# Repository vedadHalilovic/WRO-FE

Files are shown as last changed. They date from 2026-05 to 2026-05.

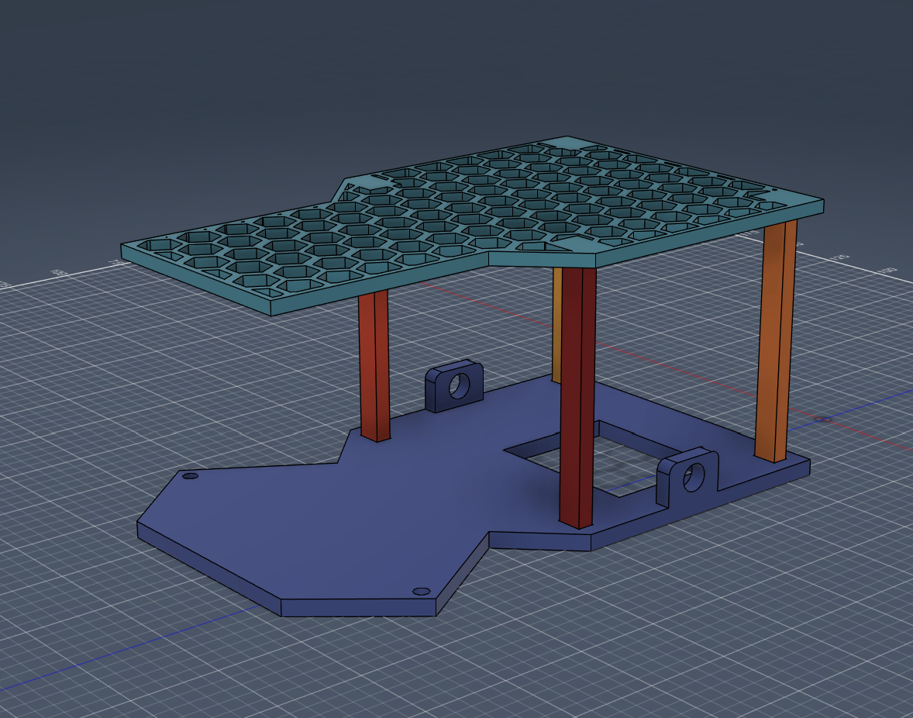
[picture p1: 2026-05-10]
models/parts/chassis/Chassis_skeleton_view.png

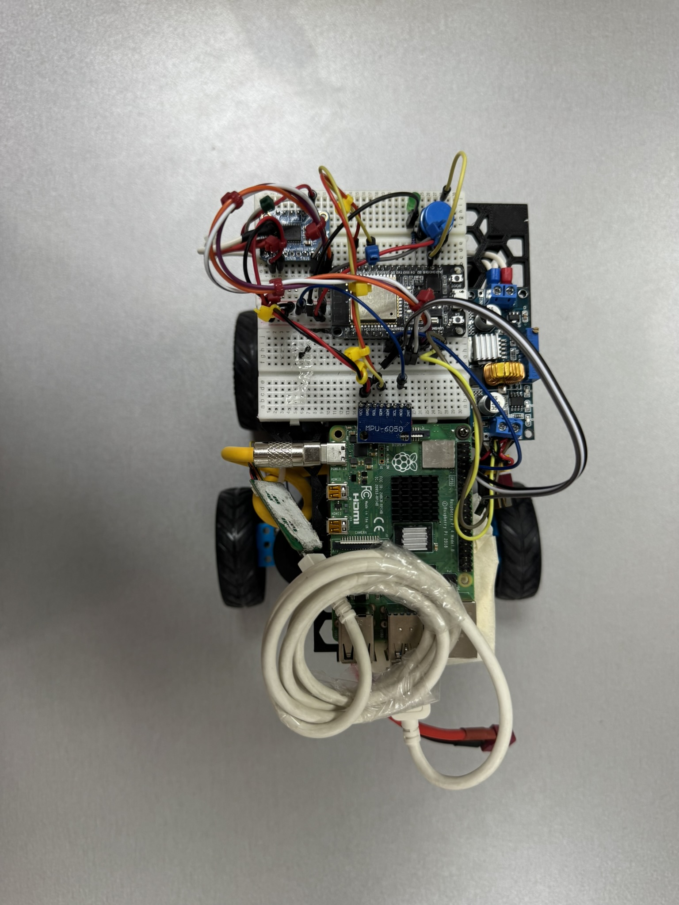
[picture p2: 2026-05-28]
v-photos/v-photo1.JPEG

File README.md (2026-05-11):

## WRO-FE

### **1.1 Team overview**

Team name: MAD Robots

**Team members:**

- Vedad Halilovic-3rd grade of Electrotechnical school in Tuzla

Responsible for construction, electronics, ESP32 code (implementation of said electronics), documentation.

- Ahmed Imsiragic-3rd grade of Mesa Selimovic gymnasium in Tuzla

Responsible for RPI code(python) development and debugging, LIDAR and camera implementation.

- Emir Mujezinovic-3rd grade of Mesa Selimovic gymnasium in Tuzla

**Team mentors:**

- Dejan Bojic- electrical engineer

Responsible for communication with competition organizers.

- Ivan Bosankic-electrical engineer

Responsible for supplying parts and tools.

### **1.2 Mission objectives**

The robot we will be talking about is built to regulations provided by WRO association, as a part of the WRO Future Engineers category.

Our task was to make a self-driving car that will be tested through two rounds, first round where it navigates around a clear track, also known as a free run/open track and a second round where there are added obstacles that need to be avoided accordingly. We achieved this by using a suite of sensors and of course the accompanying code.

The robot's uniqueness lies in it's guidance system, where it uses LIDAR for driving straight and avoiding obstacles as well as using a gyro for 90 degree turns and a camera for detecting obstacle colours. We combined this with RPI 4 model B which takes the raw data from LIDAR and camera and generates navigation data that is further executed by the ESP32 that receives the data and using it controls the steer and drive components (servo and DC motor).

## **Car description**

### **2.1 Challenge 1-open track**

- LIDAR detects walls so the robot stays centerlined and detects an incoming turn.
- RPI generates navigation data in degrees and sends it to the ESP32 and ensures that the robot completes 3 laps and stops in the right spot.
- ESP steers the car according to the data from RPI to keep the robot centerlined and when needed initiate a 90-degree turn
- MPU6050 tracks the yaw and ensures that the robot turned 90 degrees left or right.

### **Challenge 2-obstacle course**

- The robot starts from a parking spot using the logic implemented in the code to navigate out of the said spot.
- Uses LIDAR to keep centreline and to detect obstacles and turns.
- To differentiate two types of obstacles we use a Pi cam module, based on whose data robot knows to go left or right of the obstacle.

### **2.3 Hardware components**

Electronic components that were needed are as follows:

| Component | Function | Model | Mounting/notes |
| --- | --- | --- | --- |
| LIDAR | Keeping the robot centerlined, detecting obstacles | RPLIDAR A1 | Mounted using the provided standoffs and securing it to the base of the construction with M3 bolts |
| Raspberry Pi 4 | Main controller | Pi 4 model B 8GB | Mounted to the top deck of the construction using two M3 bolts |
| AZ-Delivery ESP32 | Gyro/motor controller | ESP32 NodeMCU Module WLAN WiFi Development Board Dev Kit C V2 with CP2102 | Mounted to breadboard |
| Servo motor | Steering the robot by turning the steer wheels | Hitec HS-422 | Mounted using a custom made bracket, for fasteners M3 and M4 bolts with corresponding nuts were used |
| 12V DC drive motor  | Driving/propelling the robot | 25GA-370 | Mounted using PETG 3D printed mount and secured to the lower deck/base of the construction using M3 bolts and adhesive |
| Motor driver | Controls the motors using PWM signals received from the ESP32 and powering the drive motor from the 11-12V source(battery) | Adafruit TB6612 motor driver | Mounted to breadboard |
| MPU-6050 | Used to determine when the 90-degree turn is achieved | MPU-6050 | Mounted to breadboard |
| Buck converter | Stepping the voltage from 11-12V to 5V suitable for 5V logic electronics | 5A high current | Mounted using adhesive to the top deck of the construction |
| 11.1V Li-Po battery | Powering the robot | GOLDBAT 11.1V 5000mAh 3S 50C LiPo RC Battery | Mounted using adhesive |
| Pi camera | Detecting the obstacle colour | Raspberry Pi Camera Module 2 | Mounted to the top deck |

### **2.4** **Mechanical design**
<p align = "center">
  iso_front_view
</p>

- **Base/lower deck:** solid PETG 3D printed part.
- **Top deck:** PETG 3D printed with honeycomb pattern for weight savings, attached to lower deck using four 3D printed pillars.
- **Camera mount:** 3D printed beam attached to the top deck using adhesive, camera is pointed down at a 15-degree angle for more accurate readings with less ambient light interference.
- **Cooling system:** heatsinks on RPI and buck converter.
- **Fasteners:** M3 and M4 bolts with corresponding nuts.
- **Drivetrain:** connected to drive wheels using ⌀4mm D-shaped axle(shaft) with a 3D printed spur gear (module 2, 10 teeth) with the same being connected to the motor with a 14 teeth module 2 spur gear. Driveshaft side movement limited using ⌀4mm shaft collars.
- **Steering system:** Steering system uses a combination of 3D printed parts and pre-made aluminium profiles as well as Lego spur gears. Axles are 3D printed, servo is connected to one of the gears, multiple gears are used as to clear the LIDAR. Everything is mounted using M3, M4 bolts and 4mm shaft collars.

### **2.5 Electrical design**

#### **2.5.1 Buck converter**

We are using a 5A buck converter that powers all electronics with the exception being the drive motor.  
It's role is to step the voltage down, so it is safe for our controllers and sensors.  
A heatsink was installed to provide adequate cooling because of high currents.

#### **2.5.2 Buttons**

Buttons provide a way to initiate our programs without accessing the RPI remotely per the regulations. First button is used to initiate the code for the first challenge, with the second button being used for the second challenge.

 **2.5.3 Motor driver**  
 
Adafruit dual H-bridge TB-6612 motor driver was chosen because it best fit our use case, with it being compact, supporting up to 1.2A continuous on 5-13V DC.  
It controls the motor movement direction by applying 5V to AIN1 or AIN2.  
Motor speed is controlled via a PWM signal from the ESP32 to the driver's PWMA pin.

(electrical schemes are in the schemes folder)

**3 Software design**

**Language:** Python (RPI side), C++ (ESP32 side)  
**Image processing:** OpenCV

**Modules:**

- **Position tracking:** LIDAR
- **Turning:** Gyro
- **Drive control:** ESP32
- **Corrections** are made using PD-based steering

**Flowcharts:**

- **System startup:** Power on → Initialize sensors → Calibration → Ready
- **Challenge 1:** LIDAR keeping robot centred driving forward→ LIDAR detecting a turn→ gyro executing a 90-degree turn → robot completes 3 laps → stops in segment it started from
- **Challenge 2:** LIDAR keeping robot centred driving forward → LIDAR detecting an obstacle → camera turning on and detecting the colour → robot passing the obstacle on the correct side → loop until finish → stop

**Uploading the code (for reproduction purposes)**

**IDE-s used:**

- **Arduino IDE (for ESP32)**
- **Thonny (for RPI)**

**Libraries (ESP32):**

- &lt;Arduino.h&gt; - used to enable Arduino API
- &lt;ESP32Servo.h&gt; - used for servo control
- &lt;Wire.h&gt; - enables I2C communication
- &lt;Adafruit_MPU6050.h&gt; - used for interacting with/controlling the gyro

**Libraries (RPI):**

- rplidar - needed to use the LIDAR
- serial - enables communication between ESP32 and RPI
- time - enables time.sleep() function

**Uploading the code to ESP:**

After installing libraries for ESP32 you need to download ESP32 in Arduino IDE to be able to upload your code, as well as CP210X drivers.

Open Arduino IDE → connect ESP to your computer → select your ESP32 board in board manager → click the upload → after the upload has finished press the RST button on ESP32

This file in combination with the codes from src folder and schemes from schemes folder can be used to replicate our robot(feel free to try)

<br/><br/>

<br/>\*\*

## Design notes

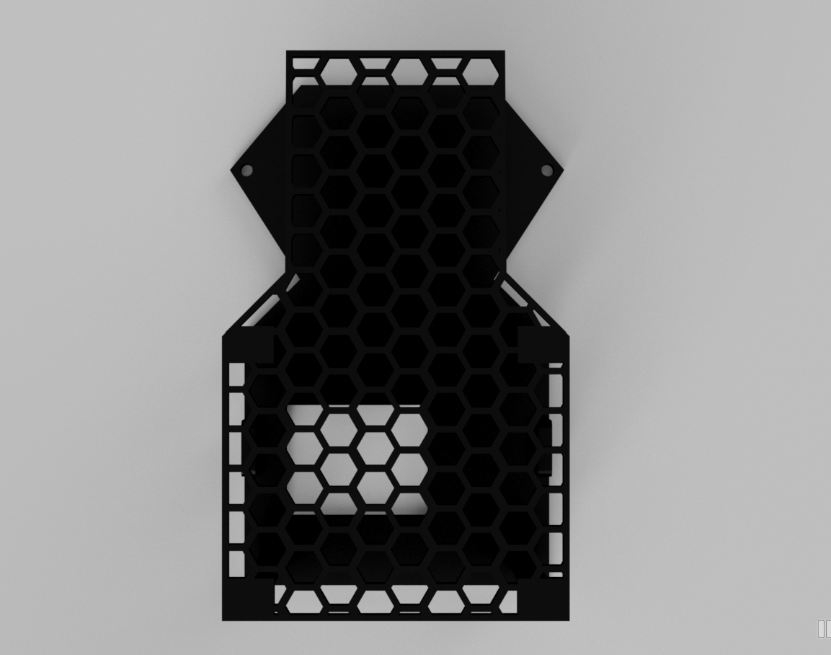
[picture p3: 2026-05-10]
models/renders/top_view_orthographic.png

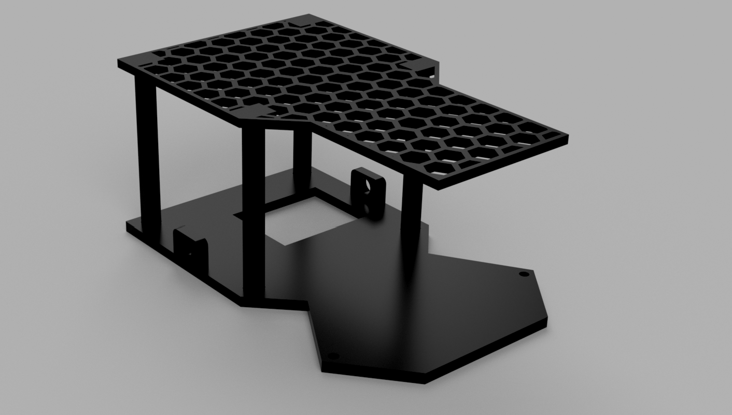
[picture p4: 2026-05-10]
models/renders/iso_front_view.png

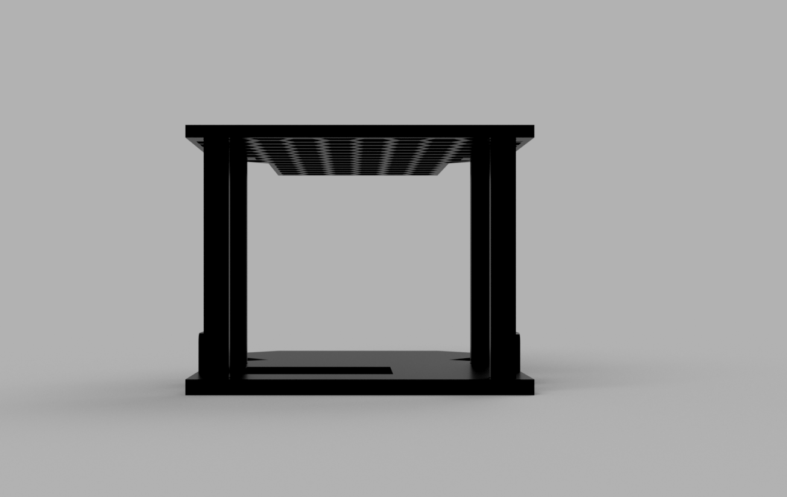
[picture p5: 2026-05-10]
models/renders/rear_view_orthographic.png

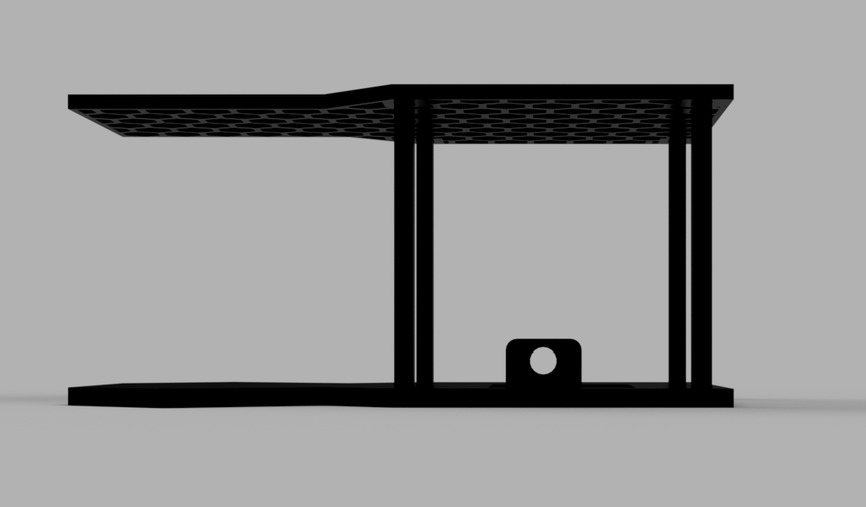
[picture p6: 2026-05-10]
models/renders/side_profile_orthographic.png

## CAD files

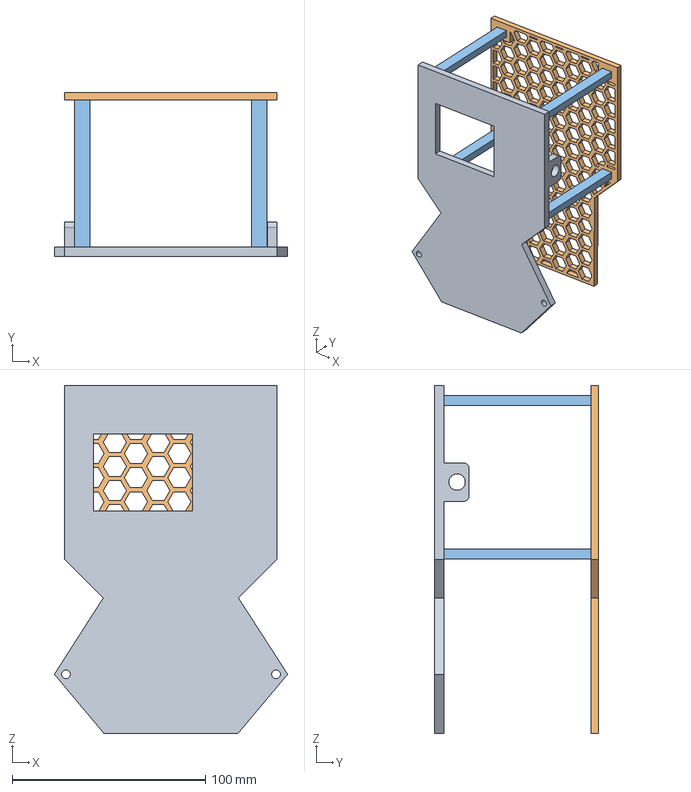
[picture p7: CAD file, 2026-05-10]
models/parts/chassis/Chassis_skeleton_view.step
120.7 x 85.0 x 180.1 mm

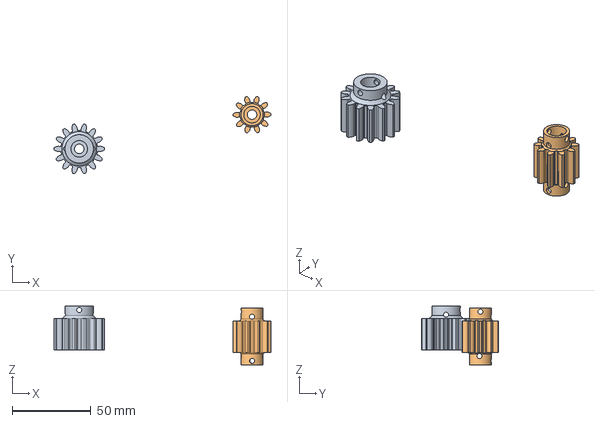
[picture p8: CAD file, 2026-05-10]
models/parts/Spur_gears/Spur_gears_design.step
137.5 x 49.0 x 37.3 mm

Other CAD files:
models/parts/Spur_gears/Spur_gears_design.3mf
models/parts/Spur_gears/Spur_gears_design.stl
models/parts/chassis/Chassis_skeleton_view.3mf
models/parts/chassis/Chassis_skeleton_view.stl

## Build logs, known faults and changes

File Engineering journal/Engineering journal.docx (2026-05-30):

# 1. Mobility & Mechanical Design

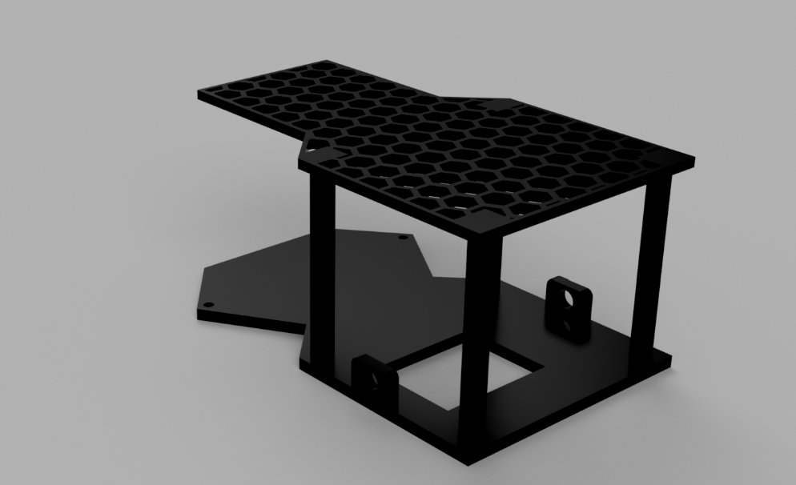
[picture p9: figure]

chassis render

As can be seen in the render above, our 2026 WRO chassis consists of two distinct parts, bottom and upper plate (lower and upper deck).

This design is a reflection of multiple constraints and insights gained through iterations. Our main constraint was the maximum width allowed per the 2026. rules which meant that the battery had to be placed on the underside of the top deck, which was not our first choice for the obvious reason of robot’s weight distribution and centre of gravity.

In the first iteration the battery was placed on the lower deck, but we knew from the start that we could not show up with that design as it measured in at 22.6cm in width, so a second chassis was designed (the one that is being described in our journal).

Key changes between the first and second iteration is the battery placement as I already mentioned, but also the maximum width as the new chassis measures in at 12.75cm at its widest point. This helps our turning radius, also the design in itself is much more efficient as less space is left unused, especially in the front half where the LIDAR is placed.

In the second iteration the honeycomb design on the bottom deck was replaced in favour of a solid PETG 3D printed surface for ease of mounting our components, while the upper deck has kept the honeycomb and has also been lengthened to accommodate the battery as well as all the sensors including the RPI and ESP32.

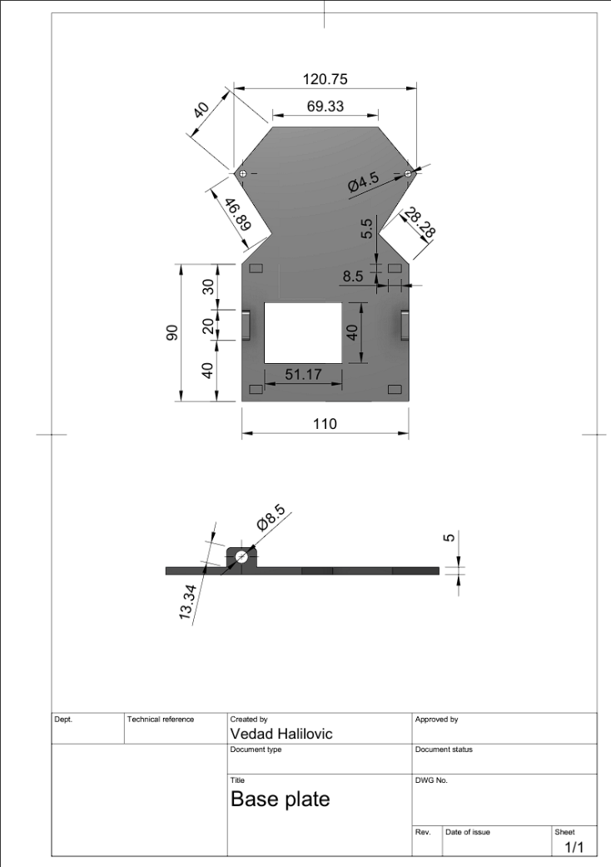
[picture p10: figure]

Technical drawing of the base plate with dimensions in 1:2 scale

With the length of 180mm(18cm) and the width of 120.75mm, this base plate fits inside the maximum allowed dimensions per the 2026. rules.

Placement of components was designed to give the robot a 60/40 weight distribution with 60% on the drive axle and 40% on steering wheels.

In the front half we placed our LIDAR on provided standoffs, so it has unobstructed 180-degree view. LIDAR is secured at 4 points using M2 bolts provided by the LIDAR manufacturer.

Under the lidar sits the first spur gear with the steering axles mounted to it using M4 bolts and corresponding nuts. Spur gear is fixed to the base plate using a 4mm stainless steel shaft, with 4mm shaft collars on both sides. Steering hubs that connect wheels to the steering system are connected to steering axles at two point parallel to one another, and to the base plate using the pre-drilled holes and M4 bolts with corresponding nuts. Holes are designed at 4.5mm in diameter due to unavoidable shrinkage associated with 3D printing.

Steering hubs are premade components, and spur gears used in the steering system are repurposed LEGO spur gears. Behind the LIDAR, servo motor is mounted. Spur gear on the servo has half the teeth compared to the spur gear connected to the steering axles. This was done to ensure a more precise system, and to reduce the stress on the servo motor itself.

In the back half of the base plate the drive motor is located on its mount. The drive motor is connected to the axle with spur gears, more precisely a 14 teeth module 2 spur gear with a 20-degree pressure angle. The spur gear is fixed to the motor with a 4mm shaft collar.

The spur gear connected to the axle is a 10 teeth module 2 and also shares the 20-degree pressure angle. This gear is fixed to the drive axle using 4mm shaft collars inside the spur gear.

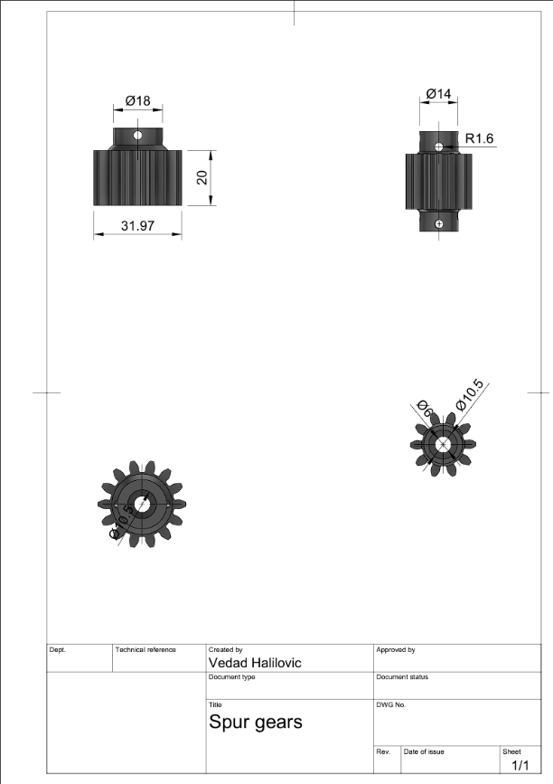
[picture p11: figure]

Spur gears drawing

As can be seen in the technical drawing above both gears share the 20mm height, as well as the inside diameter of 10.5mm, even though the shaft collar has an outside diameter of 9mm, due to shrinkage of plastics during 3D printing inner diameter of our gears was set to 10.5mm to compensate for the mentioned shrinkage.

We chose 14:10 ratio because our motor is a high torque model, which means that it comes geared from the manufactuer, and only provides 160rpm on max speed. Testing showed that the best ratio of speed and torque was offered by 14:10 ratio, we also tried 1:2 and 1:3 but during testing we found that this appreoach sacrifices too much torque and that the robot was becoming much less precise because eof this.

Module 2 was chosen because in our very first iteration of the spur gear system with the 2:1 ratio and module 1 gears were skipping a lot and that obviously created issues with movement, as the teeth would slip. That lead us to use module 2 for all other iterations and testing. We used a 20 degree pressure angle from the start, because the higher pressure angle offers stronger teeth(wider base), with a trade-off being louder operation compared to 14.5-degree pressure angle, but as that is not an important factor to us we prioritised the shear strength to avoid teeth snapping, which is also a reson for the 20mm heigth which helps us distribute the load accros the gear.

Below you will find a 3D render of the spur gears which better illustrates the design.

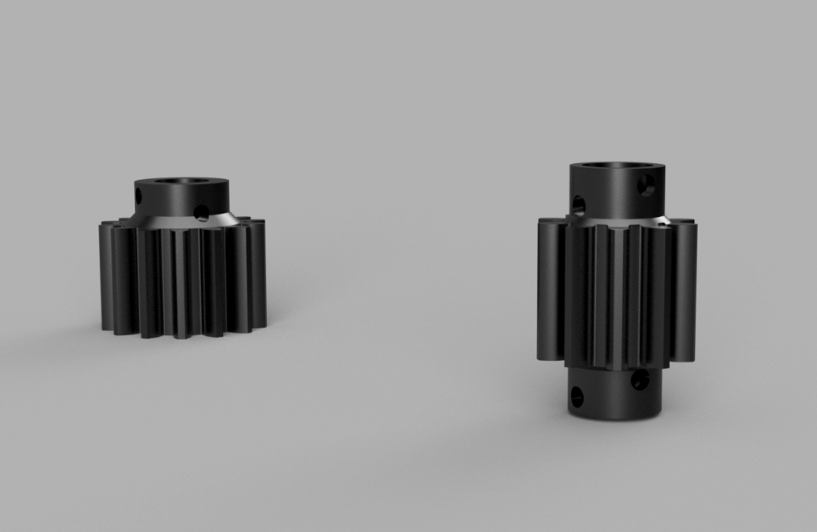
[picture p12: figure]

Spur gears render

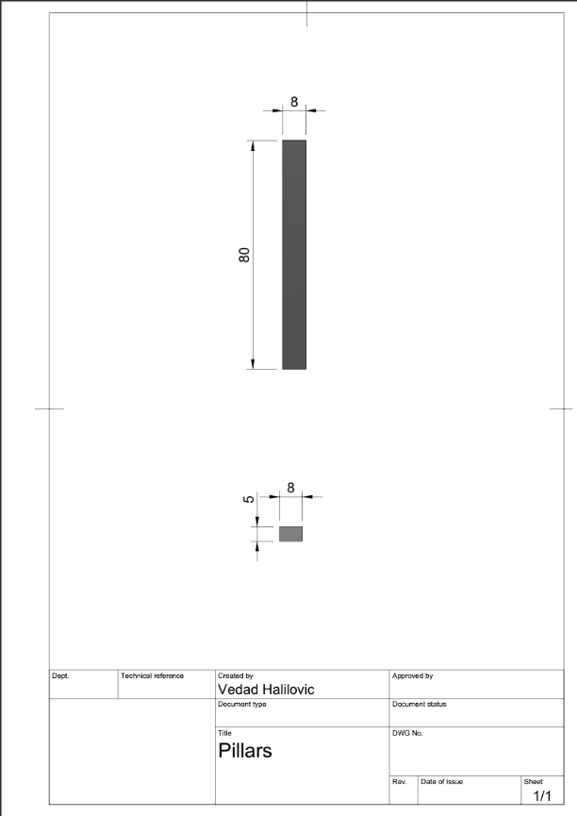
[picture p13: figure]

Pillar technical drawing

Four pillars connect the bottom and top deck of our robot. We chose an 85% infill to ensure mechanical stability so that they would not accidentally bend. They sit in the cutouts on the bottom plate, with the same cutouts being found on the top plate as well. Initially we wanted to use a lighter desing with a 20% infill, but as they have to carry the weight of the battery and not just the electronics we opted for a more heavy-duty approach.

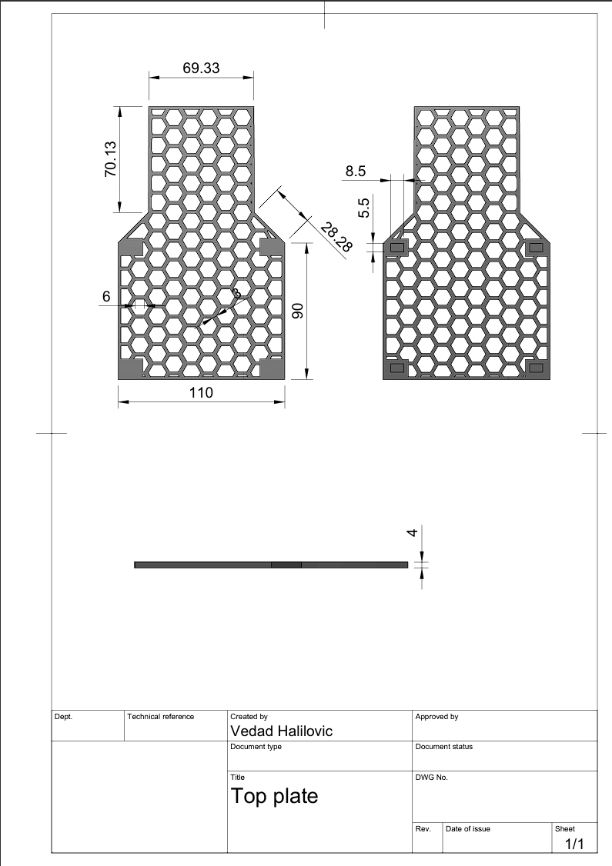
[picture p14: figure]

Top plate technical drawing

For our second iteration the top plate has been lenghtened to accommodate both the electronic components and the battery.

We went with a honeycomb design, because it offers weight savings while still giving us enough structural rigidity. For the first iteration of this desing we tried a 2mm thickness, but found that it bends too much and is prone to cracking, so for the second iteration we increased the thickness to 4mm as can be seen on the technical drawing above. For infill we went with 85% because of the dense honeycomb structure. The top plate has an overall length of 18cm, with the widest point coming in with the width of 11cm. The specific shape was chosen for space saving, that is reducing unused space, as the front half is just wide enough to fit a Raspberry Pi, with the back half being wider to accommodate other components, with the breadboard.

In the front half the RPI is placed together with the Pi camera and in the back half ESP32 with the motor driver, MPU and buck converter are placed.

# 2. Power & sensor architecture

Sensor list:

Name/manufacturer | Model | Use | Current draw
12VDC drive motor | 25GA-370 | Moving the robot | 700mA-1A
Servo motor | Hitec HS-422 | Steering the robot | 600mA-800mA
Pi camera | Raspberry Pi Camera Module 2 | Detecting the obstacle colour | 250mA-300mA
RPI 4 | Model B 8GB | Calculation of navigation data | 1A-3A
RPLIDAR | A1 | Navigation | 600mA
ESP32 | Wroom/DevKit | Management of motors and other sensors | 240mA-500mA
MPU | MPU 6050(6 axis MPU) | Calculation of 90 degree turns | 5mA
Adafruit TB6612 | TB6612FNG | PWM control of 12VDC motor | 10μA

Total system draw ranges from 3.4 – 6.2A depending on the circumstances for instance on idle it is around 3.4, while during the second-round execution 6.2A may be reached.
important to note is that 600-800mA from this sum is the DC motor which does not eat into our buck converter’s power budget.

For our battery we have chosen the GOLDBAT 5000mAh 3s LiPo battery as it offers a 250A continuous current draw, what that means for us is that our voltage does not drop even on startup or under peak loads and the battery stays cool. Only downside to running this battery is the weight penalty with the battery coming in at 429g on its own.

Since the battery has a nominal voltage of 11.1V a buck converter is needed so that the voltage could be stepped down to 5V for other electronics, while the drive motor runs directly off the 11.1V pack.

Buck converter that is being used can output 5-6A with the heatsink that is installed, because we were space constrained, we opted for one high power buck converter rather than two lower power models.

RPI was needed due to our choice of using LIDAR instead of ultrasonic sensors as LIDAR uses USB connection.

For the camera it was not as much of a necessity as it was convenient, because we figured we need the RPI for the LIDAR, we might as well use a Pi camera instead of a standalone module like openMV H7 and similar modules which was also a weight and a space saving measure. All of that combined with RPI’s computational power made it an obvious choice.

TB6612 was chosen because it is compact and much more efficient than older BJT motor drivers with minimal voltage drop due to its use of CMOS. Also, it has a smaller power draw for its own internal components which creates a smaller voltage drop on the ESP32’s 3.3V rail used to power it.

ESP32 is being used to control all the sensors with the exceptions being the Pi camera and LIDAR.
There are multiple reasons for this but the main one being that it was much easier for us to program it in two different codes one on RPI sending the navigation data and ESP32 executing it, that is communicating with said sensors.

Because the 2026 rules dictate a solid rear axle that is no differential drive it was decided to add an IMU, with reasoning that rear wheels spinning at the same speed cause the front wheels to sometimes skip, which produced inconsistencies in 90 degree turns. By adding an IMU this problem was alleviated, with the IMU tracking robot’s yaw and it keeps turning until the robot achieves 90 degrees.

Servo motor on the robot is Hitec HS-422 was chosen mainly for its availability in the region, but also for its torque which was needed to keep the steering smooth on our 1.5kg robot.

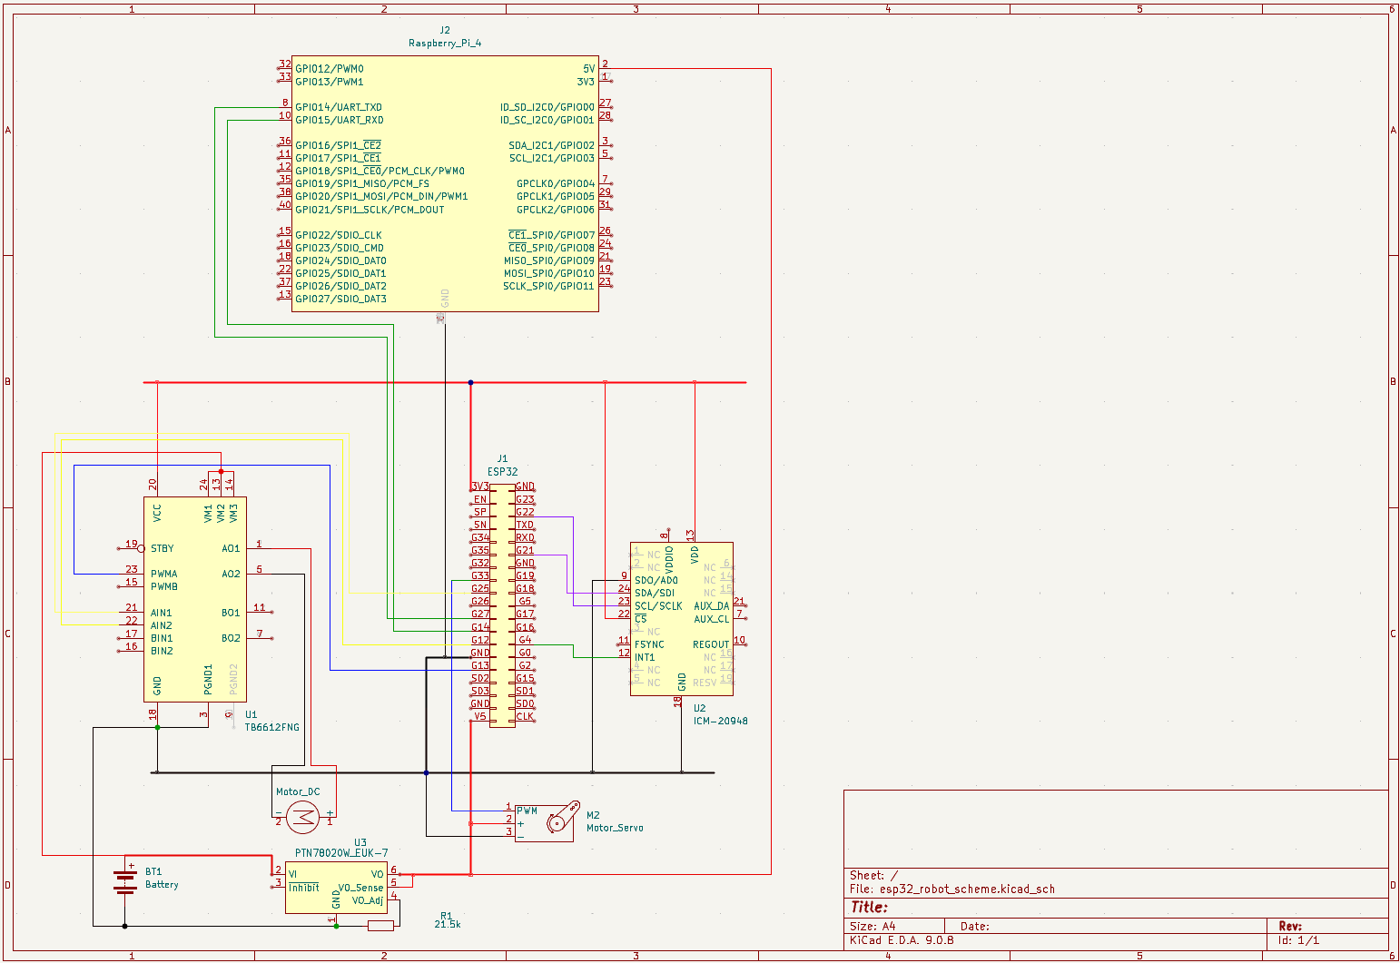
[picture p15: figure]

Electrical scheme

In the picture above is presented a wiring diagram/schematic of our robot, except for the camera and LIDAR which we could not obtain in the software that we are using (KiCAD).

As can be seen on the diagram above ESP32 and RPI communicate using TX/RX pins (pins 27, 14 on ESP32). We refrained from directly using TX/RX pins on ESP32, rather we created a virtual serial port/monitor, because we were having issues with inconsistent data transfer using UART, that led us to our unorthodox solution, as a result of which we had to switch to baud rate of 9600 from 115200. In the end the 9600bps did not limit us in any way, furthermore it allowed us to be more flexible with our pins because now we can use almost any pin on our ESP32 for communication with the RPI.

For the MPU we have decided on the I2C protocol for seamless integration with the ESP32, for the calibration we were running a 750 sample for loop as soon as the robot is powered on, during which time the robot remains stationary(both servo and drive motor are disabled) so we can get an accurate calibration with minimal, gyro drift which is further mitigated by using a filter in the updateYaw() function which is further explained in the Software Architecture & Obstacle Strategy section.

But on our second iteration we discovered a function in the library which calibrates the gyro, and also updates all 6-axis, after which we just read the axis that we need. The function in question is mpu.calcGyroOffsets(), and the function for updating the axis is mpu.update().

The TB6612FNG is connected to pins 13, 12, 25(PWMA, AIN2, AIN1). By altering PWM signals on these pins, we control the polarity(direction) and speed of our drive motor. Pins AIN1 and AIN2 control the polarity of the motor, while the PWMA controls the speed which in the code is defined as driveSpeed that is of the integer type.

VCC pin supplies the driver with 3.3V for the logic side that is for powering the transistors, important to note is that the TB6612FNG uses a shared(common) ground between the high voltage and low voltage side.

AO1 and AO2 pins are outputs of the drivers that connect to the motor’s positive and negative terminals.

VM pins supply are connected to 12V, and they supply the motor with power. As can be seen on the diagram above VM pins are connected directly to the battery bypassing the buck converter. For all 12V connections and RPI power line a 0.75mm wire is used to handle large currents without added resistance and heat.

Servo motor is using 5V from the buck converter and is grounded with all the other components. Servo’s signal wire is connected to pin 33 on ESP32. We opted for a 5V servo because it provided enough torque while being significantly lighter than its 12V counterparts.

ESP32 gets its power from the buck converter and steps it down further to 3.3V so it is safe for the IMU and TB6612FNG, it was decided to power these components directly from ESP’s 3.3V rail because the current that they draw is extremely small (measured in microamps).

RPI is powered through its type-C interface using 5V from the buck converter, as all the other components it also has a common ground so as not to cause interference in communication with ESP32 due to difference in potentials.

RPLIDAR is placed at the front of the robot so it has unobstructed 180-degree view of the track, above the LIDAR Pi camera is placed so it could reliably read colours of the obstacles.

MPU is placed on the top deck as far from the drive motor as possible as to limit the EMI, further steps have been taken to limit EMI such as twisting motor’s power lines and having the TB6612FNG on the opposite side of the breadboard also helps alleviate this issue.

Buck converter is placed on the far-right side so its heatsink gets as much cool air over it as possible to be able to passively dissipate the heat from the 5A running through it.

Placement of servo was mainly dictated by the position of the LIDAR with the servo being positioned right behind it.

ESP is placed in the middle of the top deck so as to be close both to the MPU, TB6612FNG and RPI.

3. Software Architecture & Obstacle Strategy

Open Challenge – ESP32 Actuation Layer

# 1. System Overview

The ESP32 is the robot's actuation layer. It receives high-level commands from the Raspberry Pi over UART, drives the motor and steering servo, and uses an MPU6050 gyroscope (IMU) to execute closed-loop 90° turns. The firmware is written in Arduino C++ and is structured around a non-blocking event loop with a dedicated state flag (isTurning) that separates straight-line driving from turn execution.

Architecture Summary

Layer 1 – Communication: HardwareSerial(2) receives commands from RPi at 9600 baud (RX=27, TX=14).

Layer 2 – State Control: isTurning flag gates command parsing; updateYaw() runs every loop iteration.

Layer 3 – Actuation: Servo on GPIO 33 for steering; TB6612-style driver (AIN1/AIN2/PWMA) for motor.

# 2. Hardware Pin Map

Pin / Bus | GPIO | Role
ledGreen | 2 | Status LED — blinks during startup, solid ON when ready
button_start | 15 | INPUT_PULLUP start button
pwma | 13 | Motor speed (PWM via analogWrite)
ain1 | 25 | Motor direction control A
ain2 | 12 | Motor direction control B
steeringServo | 33 | Steering servo signal
I2C SDA | 21 | MPU6050 data line
I2C SCL | 22 | MPU6050 clock line
UART2 RX | 27 | Receive from Raspberry Pi
UART2 TX | 14 | Transmit to Raspberry Pi

# 3. State Machine

The firmware operates as a four-state FSM driven by the isTurning flag and the startup sequence:

State | Entry Condition | Actions | Exit Condition
STARTUP | Power on | Blink LED; wait for button; initialise Serial, UART, I2C | Button pressed
CALIBRATE | Button pressed | mpu.calcGyroOffsets() — robot must remain still | Calibration complete
READY / DRIVE | Calibration complete; sends 'a' to RPi | Parse UART commands; apply steering angle; drive at driveSpeed | Receives 'l', 'r', 'n', or 'm'
TURNING | startTurn() called | Reduced speed; full servo lock; checkTurnProgress() each loop | yaw reaches targetYaw; sends 'h' to RPi

The isTurning flag is the central gate of the FSM. While isTurning is true, incoming UART commands are ignored completely — this prevents a new steering angle arriving mid-turn from interfering with the gyro-controlled manoeuvre.

# 4. IMU Integration — updateYaw()

The MPU6050 is used exclusively for yaw (Z-axis rotation) tracking. It is updated on every loop iteration to maximise angular resolution during turns:

void updateYaw() {

mpu.update();

yaw = mpu.getGyroAngleZ(); // integrated gyro angle in degrees

static float lastPrintedYaw = 0;

if (abs(yaw - lastPrintedYaw) > 0.5) { // only print on meaningful change

Serial.print("Current Yaw: ");

Serial.println(yaw);

lastPrintedYaw = yaw;

}

}

mpu.getGyroAngleZ() returns an accumulated (integrated) angle — it measures rotation relative to the heading at power-on, not absolute compass bearing. This is ideal for 90° turn control because only the change in heading matters. The 0.5° print threshold prevents the debug serial from being spammed on every loop while still logging every meaningful heading change. Gyro offsets are calculated once at startup via mpu.calcGyroOffsets(true) with the robot stationary, which removes the systematic drift component from the integration.

# 5. Turn Execution Algorithm

## 5.1 Turn Initiation — startTurn()

void startTurn() {

isTurning = true;

driveForward(driveSpeed - 35); // reduce speed: 130 - 35 = 95 PWM

if (turnDirection == 1) steeringServo.write(40); // full left lock

else if (turnDirection == -1) steeringServo.write(150); // full right lock

}

Speed is reduced by 35 PWM counts during turns to improve gyro tracking accuracy and reduce centrifugal forces on the chassis. The servo is immediately set to full lock (40 for left, 150 for right) to begin rotating as aggressively as possible at the start of the corner.

## 5.2 Proportional Turn Control — checkTurnProgress()

Rather than holding full servo lock throughout the entire turn, the algorithm applies a proportional correction that gradually straightens the wheels as the robot approaches its target heading. This reduces overshoot:

void checkTurnProgress() {

if (turnDirection == 1) { // left turn

if (yaw > targetYaw) { // still turning

int turnAngle = round(minL - (k * (yaw - targetYaw)));

steeringServo.write(constrain(turnAngle, 40, 80));

} else { turnComplete = true; }

} else if (turnDirection == -1) { // right turn

if (yaw < targetYaw) {

int turnAngle = round(minR - (k * (yaw - targetYaw)));

steeringServo.write(constrain(turnAngle, 110, 150));

} else { turnComplete = true; }

}

}

The control law for each direction is explained below:

Parameter | Value | Meaning
k | 0.33 | Proportional gain — controls how quickly the servo straightens as the target approaches
minL | 76.0 | Left servo near-neutral angle — the angle the servo approaches as error → 0
minR | 114.0 | Right servo near-neutral angle — symmetric to minL around the centre (96°)
constrain left | [40, 80] | Hard limits the left-turn servo: never beyond full lock, never past near-neutral
constrain right | [110, 150] | Hard limits the right-turn servo: symmetric safety bounds

Left turn example: targetYaw = yaw_initial - 90. While yaw > targetYaw, the error (yaw - targetYaw) is positive and shrinking. turnAngle = 76 - 0.33 * error: when error is large the angle goes below 76 (more leftward lock); as error shrinks toward zero, turnAngle approaches 76 (near-neutral). The result is a smooth steering unwind that reduces the chance of the robot swinging past the target heading.

Right turn example: targetYaw = yaw_initial + 90. While yaw < targetYaw, (yaw - targetYaw) is negative, so -k*(negative) is positive: turnAngle = 114 + 0.33 * |error|. When error is large, angle goes toward 150 (full right lock); as error shrinks, it approaches 114 (near-neutral). Constrained to [110, 150].

# 6. Command Protocol

All communication uses newline-terminated ASCII strings at 9600 baud over HardwareSerial(2):

Direction | Command | Action
RPi → ESP | Integer (e.g. '-14') | Map to servo range [40–150] and drive forward at driveSpeed
RPi → ESP | 'l' | Left 90° turn: targetYaw = yaw - 90, turnDirection = 1
RPi → ESP | 'r' | Right 90° turn: targetYaw = yaw + 90, turnDirection = -1
RPi → ESP | 'n' | Left 45° turn (reserved for Round 2 obstacle avoidance)
RPi → ESP | 'm' | Right 45° turn (reserved for Round 2 obstacle avoidance)
RPi → ESP | 't' | LiDAR error: stop motors for 1.1 seconds, then resume
RPi → ESP | 'e' | End of run: wait 500 ms, stop all motors
ESP → RPi | 'a' | Ready signal: calibration complete, RPi may begin scanning
ESP → RPi | 'h' | ACK: turn complete, RPi may resume LiDAR-guided driving

Steering integers are received in the range [-90, 90] and remapped to servo positions using Arduino's map() function: map(incomingAngle, -90, 90, 40, 150). The servo neutral (96) sits near the midpoint of this range (95), with the 1-degree offset accounting for mechanical centre trim. Commands 'n' and 'm' (45° turns) are implemented and tested but not invoked by the Round 1 RPi code — they are pre-built for Round 2 obstacle avoidance.

# 7. Startup & Calibration Sequence

void setup() {

pinMode(button_start, INPUT_PULLUP);

while (button_start == HIGH) { // blink LED while waiting

digitalWrite(ledGreen, HIGH); delay(500);

digitalWrite(ledGreen, LOW); delay(500);

}

delay(1000);

Serial.begin(115200); // debug USB serial

mySerial.begin(9600, SERIAL_8N1, 27, 14); // RPi UART

Wire.begin(21, 22);

mpu.begin();

mpu.calcGyroOffsets(true); // robot must be stationary

steeringServo.attach(33);

stopAll();

steeringServo.write(96); // centre steering

digitalWrite(ledGreen, HIGH); // solid ON = ready

mySerial.println("a"); // notify RPi

}

The startup sequence is deliberately ordered: the button gate comes first so the operator can position the robot before any initialisation begins. The gyro calibration (mpu.calcGyroOffsets) takes several seconds and requires the robot to be completely stationary — placing it after the button press guarantees this. The LED blinks during the wait and turns solid when ready, giving the operator a clear visual status. The 'a' message is the final action, signalling the Raspberry Pi that the ESP is calibrated and commands may begin.

# 8. Motor & Servo Control

void driveForward(int speed) {

digitalWrite(ain1, LOW);

digitalWrite(ain2, HIGH); // sets forward direction

analogWrite(pwma, speed); // PWM speed control (0-255)

}

void stopAll() {

analogWrite(pwma, 0);

digitalWrite(ain1, LOW);

digitalWrite(ain2, LOW); // both LOW = coast/brake

}

The motor driver is controlled via two direction pins (AIN1, AIN2) and one PWM speed pin (PWMA). Forward direction is AIN1=LOW, AIN2=HIGH. stopAll() sets PWM to 0 and both direction pins LOW, which puts the driver in a coast state. The normal driving speed is 130/255 PWM. During turns this is reduced to 95/255 via driveSpeed - 35, improving yaw tracking accuracy.

Servo Value | Physical Meaning
40 | Full left lock (maximum turn)
80 | Near-neutral left (used as turn completion boundary)
96 | Mechanical centre / straight ahead
114 | Near-neutral right (used as turn completion boundary)
150 | Full right lock (maximum turn)

# 9. Edge Case Handling

## 9.1 Turn Interrupt Protection

The UART read block is guarded by !isTurning. Any steering or turn command that arrives while a turn is in progress is discarded. This ensures the gyro-controlled manoeuvre completes cleanly without interference from LiDAR updates that may still be arriving from the RPi.

## 9.2 LiDAR Error Recovery — 't' Command

When the Raspberry Pi detects an RPLidar exception in safe_scans(), it sends 't' to the ESP before attempting recovery. The ESP responds by stopping the motors for 1.1 seconds. This prevents the robot from driving blind during the sensor restart window, which typically takes 0.5–1.0 seconds.

## 9.3 Servo Constraining During Turns

The proportional turn formula can theoretically produce values outside the physical servo range. The constrain() calls — [40, 80] for left and [110, 150] for right — hard-limit the output regardless of the gain k or the size of the yaw error, protecting the servo from out-of-range commands.

## 9.4 Post-Turn Settling

After a turn completes, the sequence is: servo to centre (96) → isTurning = false → 500 ms delay → send 'h' → stopAll() → 1000 ms delay. The 500 ms before sending 'h' ensures the robot has physically stopped rotating before the RPi resumes sending steering corrections. The 1000 ms stop after 'h' gives the RPi time to clean its LiDAR input buffer before the robot starts moving again.

# 10. Testing & Tuning Process

## 10.1 Gyro Calibration Verification

- Robot placed on flat surface, powered on, button pressed.
- USB serial monitor observed for 'MPU Ready and Calibrated!' message.
- Robot left stationary for 30 seconds post-calibration; yaw drift measured at < 0.3°/min, confirming offsets are valid.

## 10.2 Turn Accuracy Tuning

- k = 0.33 chosen by running turns and measuring final heading with a protractor. Lower k caused overshoot; higher k caused the servo to straighten too early and undershoot.
- minL = 76 and minR = 114 were tuned by observing the servo position at which the robot tracked straight after a turn. They are symmetric around 96 (mechanical centre).
- driveSpeed - 35 (95 PWM) was the lowest speed at which the robot reliably completed turns within the mat boundaries while still rotating fast enough to not stall.

10.3 Metrics Used to Validate Performance

Metric | How Measured | Target
Turn heading accuracy | Protractor after 12-turn run | < 5° cumulative yaw error
Turn completion time | Stopwatch from 'l'/'r' sent to 'h' received | < 3 seconds per turn
Gyro drift over 3 laps | Read final yaw after 12 turns with no movement | < 5° drift
Motor response latency | Oscilloscope on PWMA vs UART RX edge | < 10 ms
LiDAR recovery success rate | 't' command test: cut LiDAR USB mid-run | >= 4/5 recoveries

# 11. Annotated Source Code

The full ESP32 firmware is presented below in logical blocks with explanatory notes at key decision points.

## 11.1 Includes & Global State

#include <Arduino.h>

#include <ESP32Servo.h>

#include <Wire.h>

#include <MPU6050_tockn.h>

#include <cmath>

HardwareSerial mySerial(2); // UART2: RX=27, TX=14

Servo steeringServo;

MPU6050 mpu(Wire);

const double k = 0.33; // proportional turn gain

const double minL = 76.0; // left servo near-neutral

const double minR = 114.0; // right servo near-neutral

int driveSpeed = 130; // normal drive PWM (0-255)

float yaw = 0; // accumulated gyro angle (degrees)

bool isTurning = false; // FSM gate flag

float targetYaw = 0; // heading to reach during turn

int turnDirection = 0; // 1 = left, -1 = right

All mutable state is kept in global variables so it persists across loop() iterations. isTurning is the single flag that separates DRIVE state from TURNING state — it is read in loop() on every iteration.

## 11.2 setup()

void setup() {

digitalWrite(ledGreen, LOW);

pinMode(button_start, INPUT_PULLUP);

while (button_start == HIGH) { // blink while waiting for button

digitalWrite(ledGreen, HIGH); delay(500);

digitalWrite(ledGreen, LOW); delay(500);

}

delay(1000); // debounce + operator ready time

Serial.begin(115200); // USB debug serial

mySerial.begin(9600, SERIAL_8N1, 27, 14);

Wire.begin(21, 22); // I2C for MPU6050

mpu.begin();

mpu.calcGyroOffsets(true); // robot must be stationary here

steeringServo.attach(33);

stopAll();

steeringServo.write(96); // centre wheels

digitalWrite(ledGreen, HIGH); // solid = ready

mySerial.println("a"); // signal RPi: calibration complete

}

The gyro calibration is the most time-sensitive part of setup — it must happen with the robot completely stationary. Placing it after the button press guarantees this, since the operator has just finished positioning the robot. Sending 'a' as the very last action ensures the RPi never starts transmitting commands before the ESP is fully initialised.

## 11.3 loop()

void loop() {

updateYaw(); // always update IMU first

if (mySerial.available() > 0 && !isTurning) {

String data = mySerial.readStringUntil('\n');

data.trim();

if (data.length() > 0) {

if (data == "l") {

targetYaw = yaw - 90.0;

turnDirection = 1;

startTurn(); }

else if (data == "r") {

targetYaw = yaw + 90.0;

turnDirection = -1;

startTurn(); }

else if (data == "n") {

targetYaw = yaw - 45.0;

turnDirection = 1;

startTurn(); }

else if (data == "m") {

targetYaw = yaw + 45.0;

turnDirection = -1;

startTurn(); }

else if (data == "t") {

stopAll();

delay(1100); }

else if (data == "e") {

delay(500);

stopAll(); }

else { // numeric steering angle from PD controller

int servoAngle = map(data.toInt(), -90, 90, 40, 150);

steeringServo.write(servoAngle);

driveForward(driveSpeed);

}

}

}

if (isTurning) checkTurnProgress();

}

updateYaw() runs unconditionally at the top of every loop iteration — even during turns — to keep the yaw accumulation as fine-grained as possible. The UART block is skipped when isTurning is true, preventing any incoming command from overriding the turn. The else branch at the bottom handles numeric angles: map() linearly converts [-90, 90] to [40, 150] servo counts and the motor drives at full normal speed.

## 11.4 checkTurnProgress()

void checkTurnProgress() {

bool turnComplete = false;

if (turnDirection == 1) { // left turn

if (yaw > targetYaw) { // not yet reached target

int a = round(minL - (k * (yaw - targetYaw)));

steeringServo.write(constrain(a, 40, 80));

} else { turnComplete = true; }

} else if (turnDirection == -1) { // right turn

if (yaw < targetYaw) {

int a = round(minR - (k * (yaw - targetYaw)));

steeringServo.write(constrain(a, 110, 150));

} else { turnComplete = true; }

}

if (turnComplete) {

steeringServo.write(96); // centre wheels

isTurning = false;

delay(500); // let robot finish rotating

turnDirection = 0;

mySerial.println("h"); // ACK to RPi

stopAll();

delay(1000); // full stop before next straight

}

}

The proportional unwind: for a left turn, (yaw - targetYaw) starts large (~90) and shrinks to 0. The servo angle starts near 40 (full lock) and rises toward minL=76 as the turn completes. The constrain() ensures the formula never commands an illegal angle. On completion, the two-stage stop (500 ms then 'h' then 1000 ms) creates a clean handoff: the robot is physically stationary before the RPi is told to resume, and stays stationary long enough for the RPi to restart the LiDAR scan loop.

## 11.5 driveForward() & stopAll()

void driveForward(int speed) {

digitalWrite(ain1, LOW);

digitalWrite(ain2, HIGH); // forward direction

analogWrite(pwma, speed);

}

void stopAll() {

analogWrite(pwma, 0);

digitalWrite(ain1, LOW);

digitalWrite(ain2, LOW); // stop

}

Motor direction is set by the AIN1/AIN2 combination. Both LOW is the coast/brake state — the driver de-energises the motor rather than actively braking. Speed is controlled via 8-bit PWM on PWMA; 130/255 (~51% duty) is the cruising speed chosen to balance pace and LiDAR tracking stability.

Software Architecture & Obstacle Strategy

Open Challenge – Round 1

# 1. System Overview

The robot's control software runs on a Raspberry Pi and orchestrates two primary subsystems: a 360° LiDAR sensor (RPLidar) for spatial awareness, and a serial UART link to an ESP microcontroller that drives the motors and servo. The software is written in Python and follows a reactive, event-driven architecture organised into three logical layers. Key spatial constants: max LiDAR distance inside the walls ≈ 1000 mm; max distance across the open mat ≈ 3000 mm.

Architecture Summary

Layer 1 – Perception: RPLidar continuously scans the environment and yields distance/angle tuples.

Layer 2 – Decision: PD controller computes steering corrections; threshold logic detects open walls (turn triggers).

Layer 3 – Actuation: Commands are serialised as ASCII frames and sent to the ESP via UART.

# 2. State Machine

The program operates as a finite state machine (FSM) with four clearly defined states:

State | Trigger / Entry Condition | Action | Exit Condition
INIT | Program start | Clean LiDAR port, hardware reset, health check | First valid scan received
DIRECTION DETECT | INIT complete | Scan walls left & right; compare average distances | avgl ≥ 1000 mm OR avgr ≥ 1000 mm
LANE FOLLOW | After each turn completes (skreno = False) | PD correction sent every scan cycle | Open wall detected again
TURN | avgl ≥ 1000 or avgr ≥ 1000 | Stop LiDAR, send 'l'/'r' to ESP, wait for 'h' ACK | count_turns == 12 → END

The boolean flag skreno (Bosnian: 'turned') acts as the handshake gate between the Raspberry Pi and the ESP. It is set True before every turn request and cleared only when the ESP replies with the character 'h', confirming the manoeuvre is complete. This prevents the LiDAR scan loop from resuming prematurely.

# 3. Lane-Following Algorithm (PD Controller)

## 3.1 Sensor Cone Geometry

Rather than using a single point measurement, the algorithm averages all LiDAR returns that fall within two angular cones, one per side of the robot:

Side | Angular Range | Rationale
Left | 345°–360° + 0°–15° | Spans the 0°/360° discontinuity; captures the full left wall zone
Right | 165°–195° | Centred on 180° (rear-facing axis); captures the right wall zone

Averaging multiple readings per cone suppresses noise from surface reflections and moving obstacles. The count variable (initialised to 1) also prevents division-by-zero when a side returns no valid readings.

## 3.2 PD Control Law

The error signal and output are computed as follows:

error = avgr - avgl # positive → too close to right wall

res = kp * error + kd * (error - last_error) # PD output (degrees)

last_error = error # store for next derivative term

The result res is clamped to [−90, +90] degrees inside send_command() before being transmitted. Both gains were tuned empirically:

Parameter | Value | Effect & Tuning Rationale
kp | 0.05 | Proportional gain. Kept low because wall distances inside the WRO mat can be 500–1000 mm; a larger kp caused oscillation.
kd | 0.0015 | Derivative gain. Damps overshoot by reacting to the rate of change of the error. Set to ≈3% of kp to avoid amplifying LiDAR jitter.
offset | 0 | Static lateral offset (mm). Set to 0 for centred tracking; can be changed to bias the robot toward either wall.

The derivative term consistently uses (error − last_error) across all branches, giving a positive output when the error is growing and a negative output when it is shrinking, which correctly damps overshoot in both the straight and post-turn recovery phases.

# 4. Turn Detection & Obstacle Strategy

## 4.1 Open-Wall Detection

A turn is triggered when the average wall distance on either side exceeds a threshold, indicating the robot has reached a corner of the mat where there is no wall:

Threshold Logic

Left turn: avgl ≥ 1000 mm → send 'l' to ESP, increment count_turns

Right turn: avgr ≥ 1000 mm → send 'r' to ESP, increment count_turns

The 1000 mm threshold was chosen because the maximum LiDAR distance when a wall is

present is ~1000 mm. Any reading at or above this means the sensor is looking past a

corner into open space — the full mat spans up to 3000 mm — reliably indicating a turn.

## 4.2 Three-Lap Completion

WRO Future Engineers requires three complete laps (12 × 90° turns). The counter count_turns is incremented on every turn event. When count_turns reaches 12, the inner loop breaks and the program sends the 'e' (end) command to halt the robot.

Direction is locked after the first detected turn. If the first open wall is on the left the robot is declared a left-turner for all 12 remaining turns, and vice versa. This prevents the algorithm from misidentifying a corner on the far side of the mat as an instruction to change chirality mid-run.

# 5. Raspberry Pi ↔ ESP Communication Protocol

All messages are ASCII strings terminated by a newline (\n) sent at 9600 baud over UART (/dev/serial0). The protocol is minimal and deterministic:

Direction | Frame Format | Meaning
RPi → ESP | <integer>\n (e.g. '−14\n') | Steering angle in degrees; clamped to [−90, +90]
RPi → ESP | 'l'\n | Execute left 90° turn
RPi → ESP | 'r'\n | Execute right 90° turn
RPi → ESP | 'e'\n | Stop; end of run
RPi → ESP | 't'\n | LiDAR error notification; ESP holds position during sensor recovery
ESP → RPi | 'h'\n | ACK: turn complete, ready to resume

# 6. Edge Case Handling

## 6.1 LiDAR Communication Errors

The safe_scans() generator wraps the LiDAR scan loop in a try/except block. On any RPLidarException the generator:

- Calls lidar.stop() and waits 500 ms
- Calls lidar.clean_input() and waits a further 500 ms
- Restarts the scan iterator automatically — the outer while True ensures the scan loop never permanently exits due to a transient USB glitch

## 6.2 LiDAR Initialisation Race Condition

The get_clean_lidar() function performs a controlled startup sequence to avoid the common RPLidar firmware lockup:

- Forces DTR low on the raw serial port to reset the device
- Flushes both the input and output buffers before handing control to the rplidar library
- Issues a hardware reset command and polls get_health() to confirm the sensor is ready
- Falls back to a direct reconnect if the hardware reset command raises an exception

## 6.3 Division-by-Zero in Distance Averaging

Both countl and countr are initialised to 1 (not 0) before each scan, so the division avgX = sumX / countX is always safe even when no LiDAR returns fall inside a cone during a particular scan cycle.

## 6.4 Serial Timeout & Blocking Reads

The serial port is opened with timeout=1 second. The while skreno loop that waits for the 'h' acknowledgement therefore blocks for at most 1 second per readline() call, preventing an infinite hang if the ESP fails to respond.

# 7. Testing & Tuning Process

## 7.1 Methodology

All tuning was performed on the physical WRO 2025 mat. The following iterative process was used:

- Step 1 – Set kd = 0, tune kp alone until the robot tracks the centreline without steady-state offset
- Step 2 – Reintroduce kd and increase until overshoot is visibly reduced without adding jitter
- Step 3 – Adjust turn thresholds (1000 mm / 1700 mm) by running the robot into each corner and reading the logged avgL/avgR values printed to the terminal
- Step 4 – Verify 12-turn count by observing count_turns in terminal output during a full 3-lap dry run

## 7.2 Metrics Used to Validate Performance

Metric | How Measured | Target / Acceptance
Lateral offset from centre | Tape measure at mid-straight after each lap | < 5 cm average deviation
Turn detection reliability | Count false triggers per 12-turn run | 0 false triggers
Turn completion ACK time | Serial terminal timestamps | < 3 seconds per turn
Full-run completion rate | Number of clean 3-lap runs / total attempts | ≥ 4/5 runs completed
LiDAR restart frequency | Count of 'Lidar greska' prints per run | < 2 per run

# 8. Code Modularity Summary

Function / Block | Responsibility | Inputs | Outputs
get_clean_lidar() | Safe LiDAR initialisation with reset & health check | PORT_LIDAR constant | Initialised RPLidar object
safe_scans(lidar) | Fault-tolerant scan generator; auto-restarts on error | RPLidar object | Scan iterator (yields scan lists)
send_command(angle) | Encode & transmit steering angle over UART | Float (degrees) | Serial frame to ESP
turning(lorr) | Send directional turn or end command over UART | String: 'l', 'r', or 'e' | Serial frame to ESP
Direction detect loop | First-scan phase; determines turn chirality | LiDAR scan data | Sets turnl / turnr flag
Lane-follow loop (turnl) | Left-hand traffic: PD control + left-turn trigger | LiDAR scan data, skreno | Steering commands, turn events
Lane-follow loop (else) | Right-hand traffic: PD control + right-turn trigger | LiDAR scan data, skreno | Steering commands, turn events

# 9. Software Flow Diagram

The diagram below illustrates the complete execution flow of the Round 1 software:

Execution Flow (text representation)

START

└─► get_clean_lidar() → Serial port open

└─► DIRECTION DETECT LOOP (safe_scans)

├─ PD correction → send_command(res)

├─ avgl ≥ 1000 → turning('l') → wait ACK → turnl = True → BREAK

└─ avgr ≥ 1000 → turning('r') → wait ACK → turnr = True → BREAK

└─► LANE-FOLLOW LOOP (safe_scans, 12-turn limit)

├─ [TURN detected] → lidar.stop() → turning() → wait ACK → count_turns++

│ └─ count_turns == 12 → BREAK

└─ [STRAIGHT] → PD correction → send_command(res)

└─► turning('e') → lidar.disconnect() → END

# 10. Annotated Source Code

The full Round 1 program is presented below in logical blocks. Explanatory notes appear between blocks where the rubric criteria — algorithm justification, state machine rationale, edge-case handling — benefit from direct reference to the code.

## 10.1 Imports & Configuration

import rplidar

import serial

import time

PORT_LIDAR = "/dev/ttyUSB0"

PORT_SERIAL = "/dev/serial0"

BAUDRATE = 9600

lidar = rplidar.RPLidar(PORT_LIDAR, 256000)

ser = serial.Serial(PORT_SERIAL, BAUDRATE, timeout=1)

time.sleep(2)

The LiDAR communicates at 256 000 baud over USB; the ESP link uses 9 600 baud over the Pi's hardware UART. The 2-second sleep allows both devices to finish booting before commands are issued. timeout=1 on the serial port ensures readline() never blocks permanently if the ESP stalls.

## 10.2 PD Controller Constants

kp = 0.05 # proportional gain

kd = 0.0015 # derivative gain

offset = 0 # lateral wall bias (mm)

last_error = 0 # stores previous error for derivative term

kp and kd were tuned empirically on the physical mat (see Section 7). offset is a static lateral bias — positive shifts the robot toward the right wall, negative toward the left. last_error is initialised to 0 and updated every scan cycle.

## 10.3 LiDAR Initialisation — get_clean_lidar()

def get_clean_lidar():

raw_ser = serial.Serial(PORT_LIDAR, baudrate=256000, timeout=1)

raw_ser.setDTR(False) # pull DTR low — forces hardware reset on USB bridge

time.sleep(0.1)

raw_ser.reset_input_buffer() # flush stale bytes left from previous run

raw_ser.reset_output_buffer()

raw_ser.close()

obj = rplidar.RPLidar(PORT_LIDAR)

try:

obj.reset() # send firmware reset command to sensor

time.sleep(2) # wait for sensor to reboot fully

obj.get_health() # confirm sensor reports OK before returning

return obj

except rplidar.RPLidarException:

obj.disconnect()

return rplidar.RPLidar(PORT_LIDAR) # fallback: cold reconnect

Opening the port and pulling DTR low resets the USB-UART bridge before the rplidar library takes ownership — this prevents a lockup where the sensor is left mid-scan from a previous run. The health check confirms the sensor is responsive before scanning begins. If the firmware reset throws an exception, the function falls back to a clean reconnect rather than crashing.

## 10.4 Fault-Tolerant Scan Generator — safe_scans()

def safe_scans(lidar):

while True: # infinite retry loop

try:

for scan in lidar.iter_scans(): #iter_scans() calls start() internally

yield scan

except rplidar.RPLidarException as e:

print(f"Lidar greska: {e}, ciscenje i restart")

try:

lidar.stop()

time.sleep(0.5)

lidar.clean_input() # flush corrupted bytes from buffer

time.sleep(0.5)

except:

pass #ignore secondary errors during cleanup

safe_scans() is a Python generator that wraps iter_scans() in an infinite retry loop. On any RPLidarException it flushes the sensor buffer and waits before retrying. Because iter_scans() internally calls start_motor() and start() each time it is entered, the retry is self-healing without needing an explicit lidar.start() call. The bare except on the cleanup block ensures a secondary failure during recovery does not crash the program.

## 10.5 Communication Functions

def send_command(angle):

angle = int(max(-90, min(90, angle))) # hard-clamp to servo range

ser.write(f"{angle}\n".encode())

def turning(lorr):

ser.write(f"{lorr}\n".encode()) # sends 'l', 'r', or 'e'

send_command() clamps the PD output to [−90, +90] before transmission, protecting the servo from out-of-range values during large transient errors (e.g. immediately after a turn). turning() sends single-character directional commands using the same newline-delimited ASCII protocol.

## 10.6 Sensor Cone Geometry Variables

minl1, maxl1 = 345, 360 # left cone — upper arc

minl2, maxl2 = 0, 15 # left cone — lower arc (spans the 0°/360° seam)

minr, maxr = 165, 195 # right cone — centred on 180° (robot rear)

The left cone is split into two arcs to handle the 0°/360° discontinuity in the LiDAR angle output cleanly. The right cone is centred on 180° and spans 30° total to collect enough returns per scan for a stable average even at speed.

## 10.7 Direction Detection — State: DIRECTION DETECT

lidar.stop()

time.sleep(1)

lidar.clean_input() # discard stale data before first scan

time.sleep(0.5) # extra settling time for the USB buffer

for scan in safe_scans(lidar):

suml = 0 ; countl = 1 # reset per scan; countl=1 prevents division-by-zero

sumr = 0 ; countr = 1

for (_, angle, distance) in scan:

if (angle > minl1 and angle < maxl1) or (angle > minl2 and angle < maxl2):

suml += distance ; countl += 1

if angle > minr and angle < maxr:

sumr += distance ; countr += 1

avgr = sumr / countr

avgl = suml / countl

error = avgr - avgl # positive = closer to left wall, steer right

res = kp * error + kd * (error - last_error) # PD control law

last_error = error

send_command(res)

The robot steers and averages distances simultaneously every scan cycle. error = avgr − avgl: when the robot drifts left the right wall appears farther away, producing a positive error and a rightward correction. The derivative term (error − last_error) damps overshoot by reducing the output as the error shrinks.

if avgl >= 1000: # left wall gone — open corner detected

lidar.stop()

turnl = True # lock chirality to left for all 12 turns

turning('l')

count_turns += 1

while skreno == True: # block until ESP confirms turn complete

line = ser.readline().decode('utf-8').strip()

if line == "h":

skreno = False

lidar.clean_input()

time.sleep(0.2) # brief pause to let robot clear the corner

break

if avgr >= 1000: # mirror logic for right chirality

Any average distance at or above 1000 mm means the sensor is reading into open space — the maximum distance with a wall present is ~1000 mm, while the open mat extends up to 3000 mm. The robot locks its chirality (turnl/turnr flag) for the entire run. The skreno handshake guarantees scanning does not resume until the ESP has finished executing the turn.

## 10.8 Lane-Follow Loop — Left Chirality

if turnl == True:

while count_turns < 12: # outer loop: one iteration per straight+turn

skreno = True

for scan in safe_scans(lidar): # re-enters iter_scans cleanly each turn

# (same cone accumulation)

if avgl >= 1000:

lidar.stop()

turning("l")

count_turns += 1

while skreno == True:

line = ser.readline().decode('utf-8').strip()

if line == "h":

skreno = False

lidar.clean_input()

skreno = True

avgl = 0 # zero average to prevent immediate re-trigger

time.sleep(0.2) # settle before next scan cycle

break # exit for-loop; while re-enters safe_scans

else:

error = avgr - avgl - offset

res = kp * error + kd * (error - last_error)

last_error = error

send_command(res)

The outer while loop is the key structural change from the previous version. Instead of a single long for-loop with a break-on-12 check inside, each iteration of while count_turns < 12 calls safe_scans() fresh — re-entering iter_scans() and restarting the LiDAR scan cleanly after every turn. When a corner fires, avgl is zeroed before breaking so the very first scan of the next while iteration cannot falsely re-trigger the turn. The 0.2 s sleep gives the robot time to physically clear the corner.

## 10.9 Lane-Follow Loop — Right Chirality

else:

while count_turns < 12:

skreno = True

for scan in safe_scans(lidar):

# (same accumulation)

if avgr >= 1000:

lidar.stop()

turning("r")

count_turns += 1

# (same skreno handshake)

skreno = True

avgr = 0 # reset to prevent re-trigger

time.sleep(0.2)

break

else:

error = avgr - avgl + offset

res = kp * error + kd * (error - last_error)

last_error = error

send_command(res)

Structurally identical to the left loop. avgr is zeroed after each turn for the same re-trigger protection. The offset sign is flipped: a positive offset increases the error term, biasing the robot toward the right wall, consistent with the right-hand circuit geometry.

## 10.10 End of Run

turning("e") # stop command to ESP

lidar.disconnect() # release USB port cleanly

After the 12th turn ACK the program sends 'e' to halt the robot in the final quadrant, then disconnects the LiDAR to release the USB port.

Software Architecture & Obstacle Strategy

Obstacle Challenge – Round 2

# 1. System Overview

The Round 2 software fuses three sensing modalities — a 360° LiDAR for wall distance, a Raspberry Pi Camera for colour block detection, and a gyroscope (on the ESP32) for turn confirmation — into a unified control pipeline. The architecture extends the Round 1 PD lane-follower with a computer vision layer that dynamically biases the steering offset to navigate around red and green obstacle blocks. The camera is used in a burst mode — captured only at the start of each straight segment rather than continuously — to avoid blocking the real-time LiDAR scan loop.

Three-Layer Fusion Architecture

Layer 1 – Perception: LiDAR (wall distances) + Picamera2 (block colour, side, zone).

Layer 2 – Decision: PD controller + block-derived offset (prva_kocka/druga_kocka).

Layer 3 – Actuation: Steering angle + turn commands sent to ESP32 via UART.

# 2. State Machine

State | Entry Condition | Actions | Exit Condition
INIT | Program start | LiDAR reset; camera warm-up (1 s); initial scan_frame(); direction determined | Blocks visible OR no blocks → LiDAR fallback
DIRECTION DETECT (camera) | Blocks detected in initial frame | Block side determines turnl/turnr; obilazenje() sets first offsets | turnl or turnr flag set
DIRECTION DETECT (LiDAR) | No blocks in initial frame | LiDAR wall scan + PD correction until avgl/avgr >= 1000 | First open wall detected
LANE FOLLOW + AVOIDANCE | Direction locked | PD + block offset; camera burst per straight (lap 1 only); gyro proximity switching | count_turns == 12
END | count_turns == 12 | turning('e'); lidar.disconnect() | Program exits

The key architectural decision is that direction detection is camera-first: if any block is visible in the opening frame, its side (left or right) directly determines the robot's chirality for the entire run. Only if no blocks are visible does the program fall back to the Round 1 LiDAR wall-detection method. This is faster and more reliable because the first corner's block colour is always visible at the start position.

# 3. Computer Vision Pipeline

## 3.1 Camera Configuration

The Picamera2 is configured for 640 x 480 RGB888 at startup but is not left running continuously. It is started immediately before a scan_frame() call and stopped immediately after, which frees the Raspberry Pi CPU for the LiDAR loop during driving. The 0.5–1.0 s warm-up delay before capture accounts for automatic exposure settling.

## 3.2 Frame Segmentation

Each captured frame is split vertically at x = 320 (the horizontal midpoint). The left half (x: 0–319) and right half (x: 320–639) are processed independently. This avoids the need for spatial localisation — a block's side is determined entirely by which half of the frame it appears in.

## 3.3 Colour Masking — build_colour_mask()

Colour detection is performed in HSV colour space, which is more robust to lighting variation than RGB. Red requires two ranges because it wraps around the 0°/360° hue boundary in HSV:

Colour | HSV Range | Notes
Red (lower) | H: 0–10, S: 120–255, V: 70–255 | Catches warm reds near 0°
Red (upper) | H: 170–180, S: 120–255, V: 70–255 | Catches cool reds near 180° (HSV wrap)
Green | H: 35–85, S: 60–255, V: 60–255 | Broad green band; S/V thresholds reject grey

A 5x5 morphological CLOSE operation is applied to each mask after thresholding. This fills small gaps within a block's silhouette caused by specular highlights or shadow edges, producing more complete and solid contours for the rectangle filter.

## 3.4 Block Detection — find_blocks() & is_rectangular()

cv2.findContours() extracts external contours from each binary mask. Each contour is passed through a two-stage filter:

- Area gate: contour area must be >= 800 pixels. This rejects noise, lens flare, and small reflections.
- Solidity gate: (contour area) / (bounding box area) must be >= 0.80. A solid rectangle scores close to 1.0; irregular shapes or partial detections score lower and are discarded.

Surviving contours are converted to bounding boxes. Distance is estimated from the bounding box height using the pinhole camera model (Section 4). Results are sorted nearest-first and capped at 2 per side per colour, limiting memory usage and processing time.

## 3.5 Distance Estimation — estimate_distance()

Block distance is estimated using the pinhole (thin lens) camera model:

distance_cm = (BLOCK_REAL_HEIGHT_CM * FOCAL_LENGTH_PX) / pixel_height

BLOCK_REAL_HEIGHT_CM = 15.0 cm is the known physical height of the WRO obstacle blocks. FOCAL_LENGTH_PX = 1000.0 was calibrated by placing a block at a known distance and measuring its pixel height: f = (pixel_height * known_distance) / real_height. The model assumes the block is always upright and fully visible — if the block is partially occluded, pixel_height is underestimated and the distance will be overestimated.

## 3.6 scan_frame() Output Format

scan_frame() returns a list of exactly 2 entries, each formatted as [colour, side, distance_cm]:

Field | Value | Meaning
colour | 1 | Green block
colour | 2 | Red block
colour | 0 | No block detected
side | 1 | Block in left half of frame
side | 2 | Block in right half of frame
side | 0 | No block
distance_cm | float | Estimated distance in cm (pinhole model)

# 4. Block Memory System

## 4.1 Storage — blocks[] and sacuvaj()

Detected blocks are stored in a global ring buffer of 8 entries: blocks[0..7], where each entry is [colour, side, zone]. The zone field discretises the continuous distance estimate into three bands:

Zone | Distance Range | Meaning
1 | < 49 cm | Close — block is in the current or approaching straight
2 | 49 – 97 cm | Medium — block is one segment ahead
3 | > 97 cm | Far — block is two or more segments ahead

sacuvaj() writes each entry from scan_frame() into blocks[blocknumber] and increments blocknumber. The zone quantisation converts the noisy continuous distance estimate into a stable 3-level signal, reducing the sensitivity of the avoidance logic to measurement noise.

## 4.2 Block Sequencing — obilazenje()

obilazenje() is the core obstacle avoidance decision function. It reads the next unprocessed block entry from the buffer and computes two steering offsets:

- prva_kocka ('first block') — the offset applied while approaching the current block.
- druga_kocka ('second block') — the offset applied after the gyro confirms the first block has been passed, pre-loading the avoidance for the next block in the same straight.
- br_kocki ('number of blocks') — 0 if no block ahead, 1 if one block, 2 if two blocks in this segment.
- distanca — the zone of the upcoming block, used to compute the LiDAR proximity trigger.

The offset sign convention is: positive offset shifts the robot toward the right wall; negative offset shifts it toward the left wall. The rules applied are:

Block Colour | Block Side | Offset Applied | Physical Effect
Green (1) | Left (1) | -offsetmax | Large leftward shift — pass green block on its right (outer side)
Green (1) | Right (2) | -offsetmin | Small leftward shift — green already partly right, minor correction
Red (2) | Left (1) | +offsetmin | Small rightward shift — red on left, minor correction
Red (2) | Right (2) | +offsetmax | Large rightward shift — pass red block on its left (inner side)

If two blocks are present in the same segment (br_kocki = 2), obilazenje() also checks if the closer block (by distance zone) should have its offsets swapped — ensuring the robot always addresses the nearest block first.

# 5. PD Controller with Obstacle Offset

The core control law is identical in structure to Round 1 but operates with lower gains and a dynamic offset:

error = avgr - avgl - prva_kocka # bias toward correct pass side

res = kp * error + kd * (error - last_error)

Parameter | Round 1 Value | Round 2 Value | Reason for Change
kp | 0.05 | 0.02 | Lower gain prevents overcorrection when large offsets are injected by block avoidance
kd | 0.0015 | 0.0005 | Lower derivative damps the faster error changes caused by proximity-triggered offset switches
offset | fixed 0 | prva_kocka (dynamic) | Replaced by the block-derived avoidance bias computed by obilazenje()

When no block is detected (br_kocki = 0), prva_kocka = 0 and the controller reduces to the same wall-centring law as Round 1. The block offset is therefore purely additive — it layers on top of the existing lane-following behaviour rather than replacing it.

# 6. Forward LiDAR Cone & Block Proximity Trigger

A third LiDAR averaging cone, centred at 90° (directly forward), is computed every scan cycle alongside the left and right wall cones. This gives a real-time measurement of how far ahead the robot can see — used to time offset switches and camera re-scans relative to the upcoming block:

minc, maxc = 75, 105 # forward cone: 75°–105°, centred at 90°

sumc = 0 ; countc = 1 # reset each scan cycle

if angle > minc and angle < maxc:

sumc += distance ; countc += 1

avgc = sumc / countc # average forward distance (mm)

avgc is then used in two proximity windows, one per block count scenario:

Scenario | Condition | Action
Single block (br_kocki == 1) | avgc < 1500 mm AND gyro signal received | Switch prva_kocka to druga_kocka — robot has passed the first block, pre-load next offset
Two blocks (br_kocki == 2) | avgc < distanca*495 AND avgc > (distanca-1)*495 AND gyro | Rescan with camera and recompute offsets — robot is entering the zone of the second block

The 495 mm multiplier maps the zone integer (1, 2, or 3) back to approximate distances in mm: zone 1 ~ 0–490 mm, zone 2 ~ 490–970 mm, zone 3 ~ 970+ mm. The condition avgc < distanca*495 AND avgc > (distanca-1)*495 creates a narrow proximity window around the expected block zone, preventing premature or missed triggers. The gyro flag from the ESP acts as a secondary confirmation — avgc alone is not sufficient because the forward cone can read through open corners.

# 7. Camera Scheduling Strategy

The camera is not run continuously. The scheduling logic is:

When | Camera Action | Rationale
Program start | Start → capture → stop | Determine chirality from first frame
Before each straight (lap 1 only, count_turns <= 4) | Start → capture → stop | Update block buffer for upcoming segment
Immediately after each turn (lap 1 only) | Capture while LiDAR waits for ACK | Camera is already started for the turn; scan at zero extra cost
Lap 2 and 3 (count_turns > 4) | No camera | Block positions repeat; buffer from lap 1 is reused via blocknumber = count_turns * 2

After the first lap, blocknumber is reset to count_turns * 2 at the end of each obilazenje() call. This reindexes into the same 8-entry buffer using the same positions as lap 1, under the assumption that the block layout does not change between laps — which is guaranteed by WRO rules.

# 8. Turn Detection & Three-Lap Logic

Turn detection is identical to Round 1: avgl >= 1000 mm triggers a left turn and avgr >= 1000 mm triggers a right turn. The count_turns counter increments on every turn and the main while loop exits at 12. The camera is started before each turn command in lap 1 so that a fresh scan is captured while the robot waits for the ESP's 'h' ACK — effectively hiding the camera scan time inside the turn execution time.

# 9. Code Modularity Summary

Module / Function | Inputs | Outputs | Role
get_clean_lidar() | PORT_LIDAR | RPLidar object | Safe LiDAR init with DTR reset and health check
safe_scans(lidar) | RPLidar object | Scan iterator | Fault-tolerant scan generator with auto-restart
send_command(angle) | Float [-90, 90] | UART frame | Clamp and transmit steering angle to ESP
turning(lorr) | String | UART frame | Send turn or end command to ESP
estimate_distance(px_h) | Pixel height (float) | Distance (cm) | Pinhole camera model distance estimate
is_rectangular(cnt) | OpenCV contour | Bool | Area + solidity filter for block detection
find_blocks(mask, offset) | Binary mask | List of block dicts | Detect, filter, sort, and cap blocks per colour per side
build_colour_mask(hsv) | HSV frame | red_mask, green_mask | Dual-range red + single-range green HSV thresholding with morphological close
scan_frame() | None (reads picam2) | [[c,s,d],[c,s,d]] | Full vision pipeline: capture → segment → mask → detect → format
sacuvaj(detected) | scan_frame output | Writes to blocks[] | Discretise distance to zone and store in ring buffer
obilazenje(min, max) | offsetmin, offsetmax | prva_kocka, druga_kocka, br_kocki, distanca | Compute per-block avoidance offsets from buffer

# 10. Testing & Tuning Process

## 10.1 HSV Colour Calibration

- Camera pointed at each block colour under competition lighting; HSV histograms printed to terminal to find hue/saturation ranges.
- Saturation lower bound set to 120 for red (raised to 150 optionally to reject pink false positives noted in code comment).
- Green lower bound S=60 chosen to accept slightly faded blocks while rejecting grey walls.

## 10.2 Focal Length Calibration

- Block placed at measured distances (30 cm, 50 cm, 80 cm); pixel height recorded from OpenCV bounding box.
- FOCAL_LENGTH_PX = (pixel_height * distance) / BLOCK_REAL_HEIGHT_CM → average of three measurements gave 1000.

## 10.3 Offset Tuning

- offsetmin and offsetmax set by running the robot past blocks in isolation and measuring lateral clearance.
- Lower kp (0.02) and kd (0.0005) validated by confirming the robot does not oscillate when a large offset is injected.

## 10.4 Metrics Used to Validate Performance

Metric | How Measured | Target
Block detection rate | Count correct detections per 8 blocks over 5 runs | >= 7/8 per run
False positive rate | Count spurious detections on blank wall sections | 0 per run
Avoidance clearance | Ruler measurement of robot-to-block gap at closest point | >= 3 cm
Turn detection reliability | Same as Round 1 (count_turns check) | 0 missed or false turns
Camera scan time | time.time() delta around scan_frame() | < 600 ms per burst
Full 3-lap completion | Clean runs / total attempts | >= 4/5

# 11. Annotated Source Code

The program is presented below in execution order with explanations at key decision points.

## 11.1 Imports, Hardware Init & PD Constants

import cv2, numpy as np

from picamera2 import Picamera2

import time, serial, rplidar

lidar = rplidar.RPLidar(PORT_LIDAR, baudrate=256000)

ser = serial.Serial(PORT_SERIAL, 9600, timeout=1)

time.sleep(2) # boot settling time

kp = 0.02 #lower than Round 1 — large offsets need gentler proportional response

kd = 0.0005 # lower derivative — offset switches cause sharp error transients

offsetmin = 0 # small lateral bias (mm) for minor block avoidance

offsetmax = 0 # large lateral bias (mm) for significant avoidance

Both offsets start at 0 and are set during field calibration. They represent the distance in mm that the error signal is biased by — identical in mechanism to the offset variable in Round 1 but now computed dynamically per block.

## 11.2 Camera Configuration

FRAME_WIDTH, FRAME_HEIGHT = 640, 480

picam2 = Picamera2()

picam2.configure(picam2.create_preview_configuration(

main={'size': (640, 480), 'format': 'RGB888'}))

BLOCK_REAL_HEIGHT_CM = 15.0 # physical block height

FOCAL_LENGTH_PX = 1000.0 # calibrated: f = (px_h * dist) / real_h

STACKED_BLOCK_OFFSET_CM = 90.0 # known front-to-back gap when two blocks stack

MIN_BLOCK_AREA = 800 # px^2 — rejects noise

RECT_SOLIDITY_THRESHOLD = 0.80 # area/bbox ratio — rejects non-rectangular shapes

RGB888 format is used instead of YUV because OpenCV's colour conversion to HSV from RGB is simpler and avoids chroma-subsampling artefacts. The preview configuration gives the fastest capture latency on Picamera2.

## 11.3 Block Memory Buffer

blocks = [[0,0,0]] * 8 # ring buffer: [colour, side, zone]

blocknumber = 0 # write pointer

blocksdone = 0 # read pointer (obilazenje)

The 8-entry buffer holds data for 4 straights x 2 blocks per straight = 8 maximum entries per lap. After lap 1, blocknumber is reset to count_turns * 2 so the same entries are reused in laps 2 and 3 without re-scanning.

## 11.4 HSV Colour Masks & Morphology

RED_LOWER_1 = [0, 120, 70]; RED_UPPER_1 = [10, 255, 255]

RED_LOWER_2 = [170, 120, 70]; RED_UPPER_2 = [180, 255, 255]

GREEN_LOWER = [35, 60, 60]; GREEN_UPPER = [85, 255, 255]

def build_colour_mask(hsv):

red = inRange(hsv, R1_L, R1_U) | inRange(hsv, R2_L, R2_U)

green = inRange(hsv, G_L, G_U)

kernel = getStructuringElement(MORPH_RECT, (5,5))

red = morphologyEx(red, MORPH_CLOSE, kernel) # fill internal gaps

green = morphologyEx(green, MORPH_CLOSE, kernel)

return red, green

Red is split into two inRange() calls because hue wraps at 180° in OpenCV's HSV encoding. The bitwise OR combines them into a single mask. The MORPH_CLOSE operation (dilate then erode) closes small holes inside the block silhouette without expanding the outer boundary significantly.

## 11.5 Rectangle Filter & Distance Estimation

def is_rectangular(cnt):

if contourArea(cnt) < 800: return False # area gate

x,y,w,h = boundingRect(cnt)

return (contourArea(cnt) / (w*h)) >= 0.80 # solidity gate

def estimate_distance(pixel_height):

if pixel_height <= 0: return inf

return (15.0 * 1000.0) / pixel_height # pinhole model

The solidity filter is critical: a block silhouette scores 0.90–0.98; a partial detection or irregular highlight scores 0.50–0.70 and is rejected. The 0.80 threshold was chosen empirically as the boundary between reliable and unreliable detections.

## 11.6 scan_frame() — Full Vision Pipeline

def scan_frame():

frame = picam2.capture_array() # capture one frame

left = frame[:, :320] # split at x=320

right = frame[:, 320:]

l_red, l_green = build_colour_mask(cvtColor(left, BGR2HSV))

r_red, r_green = build_colour_mask(cvtColor(right, BGR2HSV))

left_info = {'RED': find_blocks(l_red, 0), 'GREEN': find_blocks(l_green, 0)}

right_info = {'RED': find_blocks(r_red, 320),'GREEN':find_blocks(r_green,320)}

detected = [[0,0,0],[0,0,0]] # always return exactly 2 entries

# fill from left_info then right_info, colour_map: GREEN=1, RED=2

return detected

The function always returns exactly 2 entries. If fewer than 2 blocks are detected the remaining entries remain [0,0,0]. This fixed-size output simplifies sacuvaj() — it always writes exactly 2 entries to the buffer regardless of scene content.

## 11.7 sacuvaj() — Distance Quantisation & Storage

def sacuvaj(detected):

for block in detected:

blocks[blocknumber][0] = block[0] # colour

blocks[blocknumber][1] = block[1] # side

if block[2] < 49: blocks[blocknumber][2] = 1 # close

elif block[2] < 97: blocks[blocknumber][2] = 2 # medium

else: blocks[blocknumber][2] = 3 # far

blocknumber += 1

The three distance zones (< 49 cm, 49–97 cm, > 97 cm) correspond to approximately half a straight, one straight, and more than one straight ahead. Zone 1 means the block is in the robot's immediate path and the full offset must be applied immediately. Zone 3 means the block is far enough that the offset can be applied gradually.

## 11.8 obilazenje() — Avoidance Offset Computation

def obilazenje(offsetmin, offsetmax):

# Determine prva_kocka from blocks[blocksdone]

if colour == GREEN and side == LEFT: prva_kocka = -offsetmax

if colour == GREEN and side == RIGHT: prva_kocka = -offsetmin

if colour == RED and side == LEFT: prva_kocka = +offsetmin

if colour == RED and side == RIGHT: prva_kocka = +offsetmax

# If two blocks: set druga_kocka for the second

# If closer block has smaller zone index: swap prva/druga

# Reset blocknumber = count_turns * 2 for lap reuse

blocksdone = (blocksdone + 1) % 8

return prva_kocka, druga_kocka, br_kocki, distanca

The sign convention: error = avgr - avgl - prva_kocka. A negative prva_kocka increases the error, causing the robot to steer left (away from the right wall). A positive prva_kocka decreases the error, steering right. Green blocks are avoided by going left; red blocks by going right, consistent with WRO obstacle rules.

## 11.9 Direction Detection — Camera-First

lidar.stop(); picam2.start(); time.sleep(1.0)

temp = scan_frame(); sacuvaj(temp); picam2.stop()

if blocks[blocknumber-1][1] == 1 or blocks[blocknumber-2][1] == 1:

turnl = True # block on left → left chirality

prva_kocka, ... = obilazenje()

elif blocks[blocknumber-1][1] == 2 or blocks[blocknumber-2][1] == 2:

turnr = True # block on right → right chirality

else:

# LiDAR fallback: scan until avgl or avgr >= 1000 (Round 1 logic)

Camera-first detection is faster and more reliable than waiting for the first LiDAR corner event. In a correctly placed starting position, at least one block is always visible in the opening frame. The LiDAR fallback exists as a safety net for edge cases where no blocks are in view at startup.

## 11.10 Main Lane-Follow Loop (Left Chirality)

while count_turns < 12:

skreno = True

if count_turns <= 4: # lap 1 only

picam2.start(); scan_frame(); sacuvaj(); picam2.stop()

prva_kocka, ... = obilazenje()

for scan in safe_scans(lidar):

suml=0; countl=1; sumr=0; countr=1; sumc=0; countc=1 # reset all accumulators

for (_,angle,distance) in scan:

if left_cone: suml+=distance; countl+=1

if right_cone: sumr+=distance; countr+=1

if angle > minc and angle < maxc: # forward cone 75-105°

sumc+=distance; countc+=1

avgl=suml/countl; avgr=sumr/countr

avgc=sumc/countc # forward clearance in mm

if avgl >= 1000: # corner detected

lidar.stop(); turning('l'); count_turns += 1

# wait for 'h' ACK

if count_turns <= 4: scan_frame() # scan during ACK wait

else:

if br_kocki == 1: # one block ahead

if gyro: prva_kocka = druga_kocka # switch after pass

else: # two blocks or none

if at_zone_distance and gyro:

scan_frame(); obilazenje() # rescan for next block

error = avgr - avgl - prva_kocka

res = kp * error + kd * (error - last_error)

send_command(res)

The one-block branch applies a proximity trigger: when avgc (the forward LiDAR reading) drops below 1500 mm and the gyro flag is set, the offset switches from prva_kocka to druga_kocka, smoothly transitioning avoidance from the current block to the next. The two-block branch uses a zone-distance check: avgc is compared to distanca * 495 (converting zone to approximate mm) to decide when to rescan and update the avoidance plan mid-straight.

## 11.11 End of Run

turning('e') # stop command to ESP

lidar.disconnect() # release USB port

Identical to Round 1. After count_turns reaches 12, 'e' halts the robot in the final quadrant and the LiDAR is disconnected cleanly.

# 4 Systems thinking and engineering decisions

One of our main constraints was the steering system.

The first iteration of our steering system used a combination of 3D printed spur gears and a micro-belt. The main issue with this approach was that the belt was prone to skipping and was very inconsistent. All this in addition to the belt stretching out has led us to seek other steering solutions. Our current solution that has proven to be much more consistent and precise than the belt approach is the use of only spur gears in a 2:1 ratio with aluminium axles and wheel hubs, which means that for every degree that the motor turns, wheels turn for 0.5 degrees. This gave us a more precise mechanism that goes hand in hand with our PD regulator that is being run on the RPI.

The only current limiting factor with this system is the maximum turning angle that our servo can provide, but nevertheless we chose this system over our first idea.

Our original idea was to run a 12V metal gear servo, but due to regional availability we had to settle for a 5V double bearing servo, but with some code optimisation and the mentioned 2:1 ratio this problem was alleviated.

Another constraint had to do with our ICM-20948 because our original idea was to use its magnetometer, which was later replaced with an approach using only a gyro due to EMI from the motors.

Unfortunately, due to an incident involving our ICM-20948 which resulted in a short circuit that fried our IMU, we were forced to replace it with an MPU-6050.

For the MPU-6050 we decided to keep our gyro approach.

Due to our choice of a high current capable battery, we took somewhat of a conscious weight penalty. With the battery sitting in at 429 grams, it is almost a third of the total weight, which we somewhat alleviated by reducing infill on non-stressed parts of the chassis and by using a honeycomb pattern on the top plate.

Another trade off related to maximum allowed dimensions was the battery placement. As our battery is quite large(5Ah) and the maximum width being limited at 20cm for the 2026. Competition, we were forced to mount the battery on the top deck.

Our first iteration of the chassis as it turned out used too small of an infill between 10 and 15%, which resulted in structural parts snapping. Also, on our second iteration we went from PLA to PETG filament and upped our infill to 40% and on our spur gears we went for 100% infill so they would not deform.

At first, we thought of using the PI camera only to determine the colour of the obstacle without their exact position which we planned to determine using our LIDAR. We decided to use the camera to determine the exact position of the blocks on the map by dissecting the camera’s field of view to two halves vertically, because we found it easier to estimate the block’s distance by its size on the picture than having to include the LIDAR in that same operation. We decided to use the LIDAR to keep our robot straight and to determine if there is a possible crash with the blocks so we can back up and dodge the block optimally without the risk of collision.

We were presented with a risk of the gyroscope being poorly calibrated which would result in a major gyro drift which would in turn make it impossible to execute precise turns. To solve this, we set a larger sample pool for the calibration (750 iterations), more importantly we assured that neither the drive motor nor the servo are running during the calibration so as to minimize or drift. The time penalty for this approach was negligible as it only takes 4 seconds to calibrate the gyro.

Because the obstacles we are supposed to avoid are red and the parking is pink, we had to adjust our mask for red blocks on camera (its HSV value) so that it would skip any blocks that were pink (red and pink are on the same side of the colour wheel). We adjusted that by a code that gives back HSV values and removed the pink threshold.

WRO Future Engineers 2026 | Page 1

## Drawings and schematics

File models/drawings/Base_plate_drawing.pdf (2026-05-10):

69.33

120.75

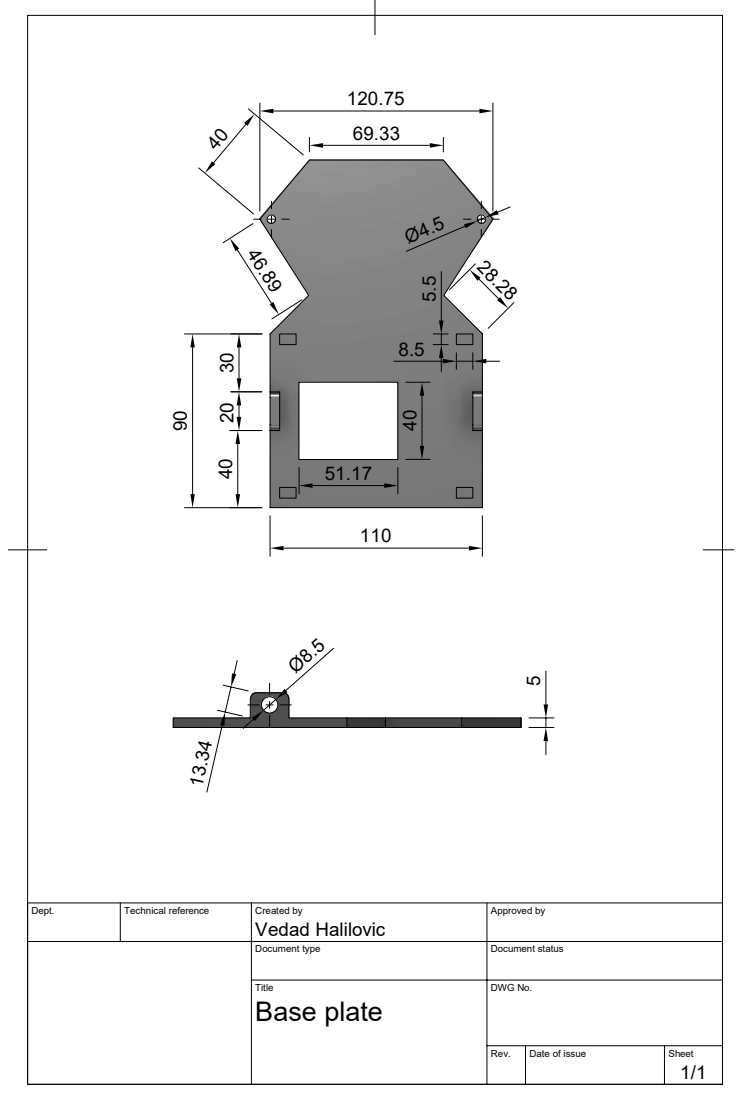
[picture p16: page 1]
Dept.; Technical reference; Created by; Approved by; Document type; Document status; Title; DWG No.; Rev.; Date of issue; Sheet; Base plate; Vedad Halilovic

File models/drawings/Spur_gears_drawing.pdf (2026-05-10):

Ø18 | Ø14

R1.6 20

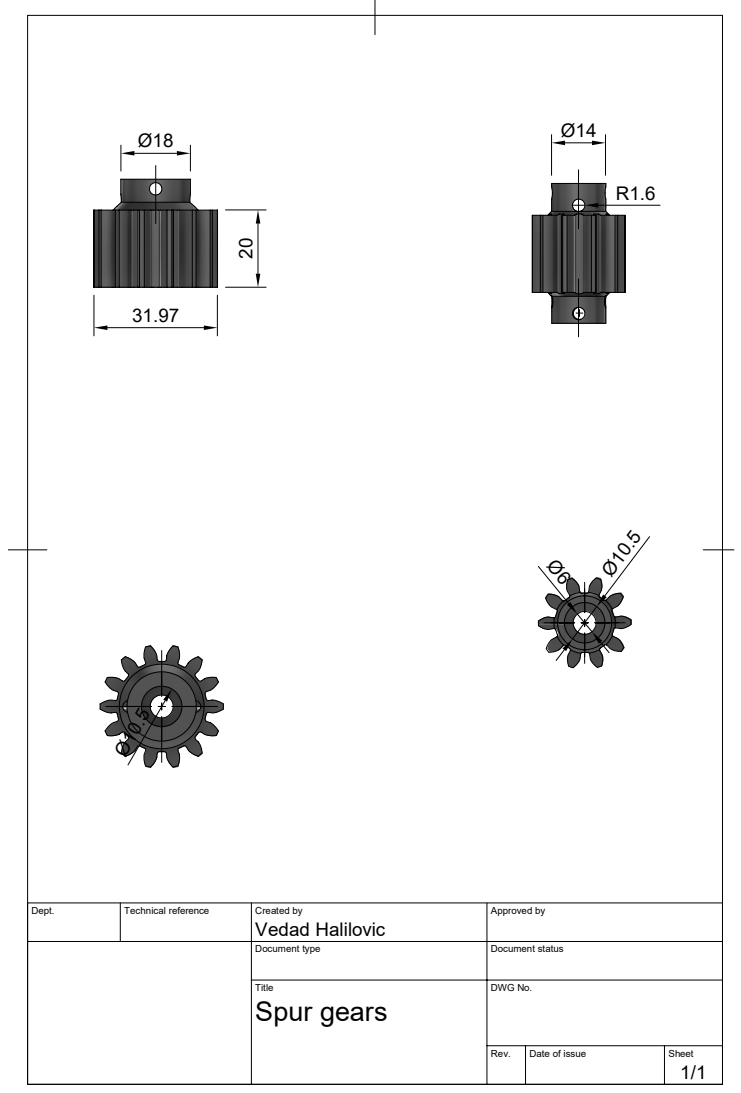
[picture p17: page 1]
Dept.; Technical reference; Created by; Approved by; Document type; Document status; Title; DWG No.; Rev.; Date of issue; Sheet; Spur gears; Vedad Halilovic

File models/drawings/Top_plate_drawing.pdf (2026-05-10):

69.33

8.5

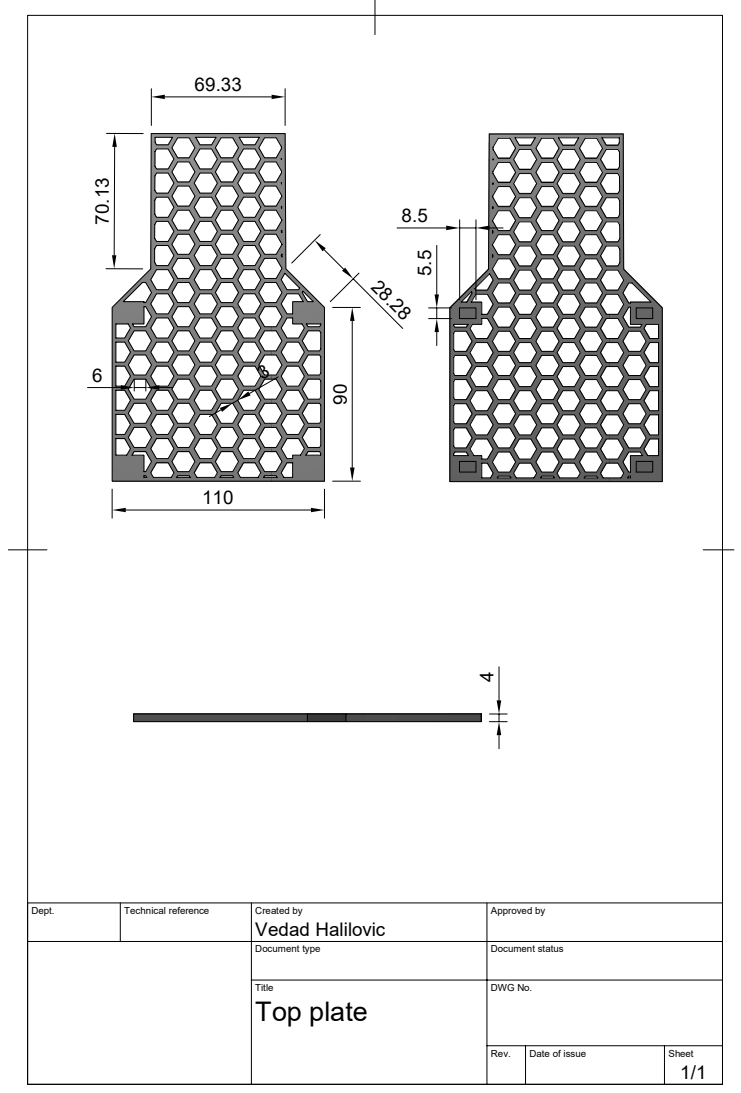
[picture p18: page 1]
Dept.; Technical reference; Created by; Approved by; Document type; Document status; Title; DWG No.; Rev.; Date of issue; Sheet; Top plate; Vedad Halilovic

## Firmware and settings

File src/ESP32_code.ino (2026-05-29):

#include <Arduino.h>
#include <ESP32Servo.h>
#include <Wire.h>
#include <MPU6050_tockn.h>
#include <cmath>

HardwareSerial mySerial(2);
Servo steeringServo;
MPU6050 mpu(Wire);

const int ledGreen = 2;
const int button_start = 15;
const int pwma = 13;
const int ain1 = 25;
const int ain2 = 12;

const double k = 0.33;
const double minL = 76.0;
const double minR = 114.0;

int driveSpeed = 130;
float yaw = 0;
bool isTurning = false;
float targetYaw = 0;
int turnDirection = 0;

void stopAll();
void driveForward(int speed);
void updateYaw();
void startTurn();
void checkTurnProgress();

void setup() {
  digitalWrite(ledGreen, LOW);
  pinMode(button_start, INPUT_PULLUP);

  while(button_start == HIGH){
    digitalWrite(ledGreen, HIGH);
    delay(500);
    digitalWrite(ledGreen, LOW);
    delay(500);
  }
  delay(1000);
  Serial.begin(115200);

  mySerial.begin(9600, SERIAL_8N1, 27, 14);

  Wire.begin(21, 22);
  mpu.begin();

  Serial.println("Calibrating... Do not move robot!");
  mpu.calcGyroOffsets(true);

  steeringServo.attach(33);
  pinMode(ain1, OUTPUT);
  pinMode(ain2, OUTPUT);
  pinMode(pwma, OUTPUT);
  pinMode(ledGreen, OUTPUT);

  stopAll();
  steeringServo.write(96);
  Serial.println("MPU Ready and Calibrated!");
  digitalWrite(ledGreen, HIGH);
  mySerial.println("a");
}

void loop() {
  updateYaw();

  if (mySerial.available() > 0 && !isTurning) {
    String data = mySerial.readStringUntil('\n');
    data.trim();

    if (data.length() > 0) {
      if (data == "l") {
        targetYaw = yaw - 90.0;
        turnDirection = 1;
        startTurn();
      } else if (data == "r") {
        targetYaw = yaw + 90.0;
        turnDirection = -1;
        startTurn();
      } else if (data == "n") {
        targetYaw = yaw - 45.0;
        turnDirection = 1;
        startTurn();
      } else if (data == "m") {
        targetYaw = yaw + 45.0;
        turnDirection = -1;
        startTurn();
      } else if (data == "t") {
        stopAll();
        delay(1100);
      } else if (data == "e") {
        delay(500);
        stopAll();
      } else {
        int incomingAngle = data.toInt();
        int servoAngle = map(incomingAngle, -90, 90, 40, 150);
        steeringServo.write(servoAngle);
        driveForward(driveSpeed);
      }
    }
  }

  if (isTurning) {
    checkTurnProgress();
  }
}

void updateYaw() {
  mpu.update();
  yaw = mpu.getGyroAngleZ();

  static float lastPrintedYaw = 0;
  if (abs(yaw - lastPrintedYaw) > 0.5) {
    Serial.print("Current Yaw: ");
    Serial.println(yaw);
    lastPrintedYaw = yaw;
  }
}

void startTurn() {
  isTurning = true;
  driveForward(driveSpeed - 35);
  if (turnDirection == 1) steeringServo.write(40);
  else if (turnDirection == -1) steeringServo.write(150);
}

void checkTurnProgress() {
  bool turnComplete = false;

  if (turnDirection == 1) {
    if (yaw > targetYaw) {
      int turnAngle = round(minL - (k * (yaw - targetYaw)));
      steeringServo.write(constrain(turnAngle, 40, 80));
    } else {
      turnComplete = true;
    }
  } else if (turnDirection == -1) {
    if (yaw < targetYaw) {
      int turnAngle = round(minR - (k * (yaw - targetYaw)));
      steeringServo.write(constrain(turnAngle, 110, 150));
    } else {
      turnComplete = true;
    }
  }

  if (turnComplete) {
    //turnCount++;
    steeringServo.write(96);
    isTurning = false;
    delay(500);
    turnDirection = 0;
    mySerial.println("h");
    stopAll();
    delay(1000);
  }
}

void driveForward(int speed) {
  digitalWrite(ain1, LOW);
  digitalWrite(ain2, HIGH);
  analogWrite(pwma, speed);
}

void stopAll() {
  analogWrite(pwma, 0);
  digitalWrite(ain1, LOW);
  digitalWrite(ain2, LOW);
}

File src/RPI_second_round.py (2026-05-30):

import cv2
import numpy as np
from picamera2 import Picamera2
import time
import serial
import rplidar
#konfiguracija
PORT_LIDAR = "/dev/ttyUSB0"
PORT_SERIAL = "/dev/serial0"
BAUDRATE = 9600   

lidar = rplidar.RPLidar(PORT_LIDAR, baudrate=256000)
ser = serial.Serial(PORT_SERIAL, BAUDRATE, timeout=1)
time.sleep(2)

#bazne konstante za lidar i kameru
kp = 0.02  # smanji jer su distance velike
kd = 0.0005
offsetmin = 170
offsetmax = 270
last_error = 0

button=False
while button==False:
    line = ser.readline().decode('utf-8').strip()
    if line=="a":
        button==True
#komande za komunikaciju izmedju rpi i esp i varijabla bool skreno koja se mijenja naspram primljene info sa esp
gyro=False
#logika za skretanja tj. stranu
#47cm je osrednja udaljenost lidara od zida unutar kocke
#105cm je otp maksimalna udaljenost lidara od zida unutar kocke
#240cm je maks duzina kada izgubi kocku
# 180 lidar pravo, 90 lijevo, 270 desno

#osnovne varijable koje se koriste u petljama za lidar
turnl=False
turnr=False
ispravljen = False
count_turns=0
skreno=True
#varijable za lijevi i desni cone lidara
minl1 = 345
maxl1=360
minl2 =0
maxl2= 15
minr=165
maxr=195
minc=75
maxc=105
prva_kocka, druga_kocka, br_kocki, distanca =0
# ─────────────────────────────────────────────
# CONFIGURATION — adjust these to your setup
# ─────────────────────────────────────────────

FRAME_WIDTH  = 640
FRAME_HEIGHT = 480
mid_x = FRAME_WIDTH // 2

picam2 = Picamera2()            # hardware, global
picam2.configure(picam2.create_preview_configuration(
main={"size": (FRAME_WIDTH, FRAME_HEIGHT), "format": "RGB888"}
))
# Real-world block height in centimeters (used for distance estimation)
BLOCK_REAL_HEIGHT_CM = 15.0

# Camera focal length in pixels — calibrate with: f = (pixel_height * distance) / real_height
# Example: if a 5 cm block appears 100px tall at 50 cm → f = (100 * 50) / 5 = 1000
FOCAL_LENGTH_PX = 1000.0

# Fixed distance offset between front and back block (cm) when one is behind the other
STACKED_BLOCK_OFFSET_CM = 90.0

# Minimum contour area to be considered a block (filters out noise)
MIN_BLOCK_AREA = 800

# How "rectangular" a contour must be (0–1). Higher = stricter rectangle check.
RECT_SOLIDITY_THRESHOLD = 0.80

# HSV colour ranges
# Red wraps around in HSV, so two ranges are needed
RED_LOWER_1  = np.array([0,   120, 70]) #sa 120 stavi na 150 radi roze
RED_UPPER_1  = np.array([10,  255, 255])
RED_LOWER_2  = np.array([170, 120, 70]) #sa 120 stavi na 150 radi roze
RED_UPPER_2  = np.array([180, 255, 255])

GREEN_LOWER  = np.array([35,  60,  60])
GREEN_UPPER  = np.array([85,  255, 255])

blocks = [[0,0,0],[0,0,0],[0,0,0],[0,0,0],[0,0,0],[0,0,0],[0,0,0],[0,0,0]]
blocknumber=0
blocksdone=0
temp =[[0,0,0],[0,0,0]]
# ─────────────────────────────────────────────
# HELPERS
# ─────────────────────────────────────────────

def get_clean_lidar():
    print("pre-cleaning serial port")
    raw_ser = serial.Serial(PORT_LIDAR, baudrate=256000, timeout=1)
    raw_ser.setDTR(False)
    time.sleep(0.1)
    raw_ser.reset_input_buffer()
    raw_ser.reset_output_buffer()
    raw_ser.close()
    obj = rplidar.RPLidar(PORT_LIDAR)
    try:
        print("Sending hardware reset command")
        obj.reset()
        time.sleep(2)
        obj.get_health()
        return(obj)
    except rplidar.RPLidarException:
        print("Hardware reset failed, trying one more time")
        obj.disconnect()
        return rplidar.RPLidar(PORT_LIDAR)
lidar=get_clean_lidar()


def safe_scans(lidar):
    while True:
        try:
            for scan in lidar.iter_scans():
                yield scan
        except rplidar.RPLidarException as e:
            print(f"Lidar greska: {e}, ciscenje i restart")
            try:
                lidar.stop()
                time.sleep(0.5)
                lidar.clean_input()
                time.sleep(0.5)
            except:
                pass

            
def send_command(angle):
    angle = int(max(-90, min(90, angle)))
    frame = f"{angle}\n"
    ser.write(frame.encode())
    print("Sent:", frame.strip())
    
def turning(lorr):
    frame = f"{lorr}\n"
    ser.write(frame.encode())
    print("Sent:", frame.strip())
print("START")

def estimate_distance(pixel_height: float) -> float:
    """Return distance in cm using the pinhole camera model."""
    if pixel_height <= 0:
        return float('inf')
    return (BLOCK_REAL_HEIGHT_CM * FOCAL_LENGTH_PX) / pixel_height


def is_rectangular(contour, threshold: float = RECT_SOLIDITY_THRESHOLD) -> bool:
    """Return True if contour is solid enough to be a rectangle."""
    area = cv2.contourArea(contour)
    if area < MIN_BLOCK_AREA:
        return False
    x, y, w, h = cv2.boundingRect(contour)
    rect_area = w * h
    if rect_area == 0:
        return False
    solidity = area / rect_area
    return solidity >= threshold


def find_blocks(mask, x_offset: int = 0):
    """
    Find rectangular blobs in a binary mask.

    Returns a list of dicts:
        { 'bbox': (x, y, w, h),   # coordinates in FULL frame
          'center': (cx, cy),
          'distance_cm': float }
    sorted by distance (nearest first).
    """
    contours, _ = cv2.findContours(mask, cv2.RETR_EXTERNAL, cv2.CHAIN_APPROX_SIMPLE)
    blocks = []

    for cnt in contours:
        if not is_rectangular(cnt):
            continue
        x, y, w, h = cv2.boundingRect(cnt)
        dist = estimate_distance(h)
        blocks.append({
            'bbox': (x + x_offset, y, w, h),   # shift back to full-frame coords
            'center': (x + x_offset + w // 2, y + h // 2),
            'distance_cm': dist,
        })

    # Sort nearest-first; limit to 2 per side
    blocks.sort(key=lambda b: b['distance_cm'])
    return blocks[:2]


def classify_stacking(blocks):
    """
    If two blocks are detected in a segment, determine whether they are
    side-by-side (unlikely given the setup) or front-to-back (stacked).
    Returns a label string for display.
    """
    if len(blocks) < 2:
        return None
    d1, d2 = blocks[0]['distance_cm'], blocks[1]['distance_cm']
    gap = abs(d2 - d1)
    # If the distance gap is close to the known fixed offset, flag as stacked
    tolerance = STACKED_BLOCK_OFFSET_CM * 0.35   # ±35 %
    if abs(gap - STACKED_BLOCK_OFFSET_CM) <= tolerance:
        return f"STACKED (gap ≈ {gap:.1f} cm)"
    return f"SEPARATE (gap = {gap:.1f} cm)"


def build_colour_mask(hsv_frame):
    """Return separate red and green binary masks."""
    red_mask = (
        cv2.inRange(hsv_frame, RED_LOWER_1, RED_UPPER_1) |
        cv2.inRange(hsv_frame, RED_LOWER_2, RED_UPPER_2)
    )
    green_mask = cv2.inRange(hsv_frame, GREEN_LOWER, GREEN_UPPER)

    # Morphological clean-up
    kernel = cv2.getStructuringElement(cv2.MORPH_RECT, (5, 5))
    red_mask   = cv2.morphologyEx(red_mask,   cv2.MORPH_CLOSE, kernel)
    green_mask = cv2.morphologyEx(green_mask, cv2.MORPH_CLOSE, kernel)

    return red_mask, green_mask
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

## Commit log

2026-03-29 RPI code for the first round
    Implement Lidar-based navigation and turning logic using RPI and RPLIDAR A1
2026-03-29 ESP32 steer/drive system
    Implementation of ESP32 with servo, IMU and DC motor for the robot's drivetrain
2026-04-13 adding electrical scheme CAD file and a photo
    [Electrical_scheme.kicad_sch]
2026-04-27 Refactor steering control and update drive parameters
    Updated motor control pins and adjusted drive speed. Modified turning logic and calibration loop.
2026-05-06 updated scheme
    servo motor added into .kicad_sch
    [esp32_robot_scheme.kicad_sch]
2026-05-10 Revise mechanical design specifications in README
    Updated mechanical design details for the base, drivetrain, and fasteners.
2026-05-10 addition of chassis files
    addition of chassis .3mf, .STEP, .STL and also .png
    [Chassis_skeleton_view.3mf, Chassis_skeleton_view.step, Chassis_skeleton_view.stl]
2026-05-10 addition of Spur_gears files
    addition of spur gears files in following formats: .STEP, .3mf, .STL and .png
    [Spur_gears_design.3mf, Spur_gears_design.step, Spur_gears_design.stl]
2026-05-11 Change sensor reference from ICM-20948 to MPU6050
    Updated sensor references from ICM-20948 to MPU6050 in the README.
2026-05-11 Replace ICM20948 with MPU6050
    Replaced ICM20948 with MPU6050 for IMU functionality. Adjusted serial communication speed and modified steering control logic.
2026-05-11 Update motor driver description for clarity
    Clarified motor driver specifications in README.
2026-05-11 Update and rename ESP32_steer.ino to ESP32_code.ino
2026-05-29 Refactor MPU6050 setup and steering control
    Updated MPU6050 initialization and calibration process. Adjusted steering angles and button handling logic.
2026-05-30 Refactor RPI_first_round.py for lidar and serial control
2026-05-30 Add Lidar and camera setup for block detection
    Implement RPi control for Lidar and camera integration.
